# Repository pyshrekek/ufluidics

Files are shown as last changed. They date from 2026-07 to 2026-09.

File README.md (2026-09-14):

# ufluidics

Firmware for an Elegoo Mega 2560 R3 driving five NEMA17 syringe pumps on a microfluidic device.

Two input pumps push a fixed total flow into the chip at a fixed ratio to each other.
Three output pumps withdraw exactly that same total, split three ways.
Two potentiometers set the output split live, and a maintained switch arms and disarms the system.

Mass balance holds by construction, not by tuning.
No pump is ever commanded directly: one total flow constant drives both inputs (by a fixed ratio) and all three outputs (by fractions that sum to 1.0).
There is one source of truth for flow in the entire program.

## Dependency

**AccelStepper** by Mike McCauley.
Arduino IDE: `Tools > Manage Libraries`, search "AccelStepper", install.

Used in constant-speed mode only.
`runSpeed()` is polled for all five pumps on every loop pass and no acceleration ramp is configured, because steady volumetric flow is the whole point and a ramp would corrupt the mass balance every time a pot moved.

## Repository layout

```
ufluidics/
  README.md          this file - the Mega firmware: wiring, calibration, verification
  HARDWARE.md        PCB spec for the ESP32-S3 revision

  arduino/ufluidics/ Mega 2560 firmware (Arduino IDE)
    ufluidics.ino
    config.h

  firmware/          ESP32-S3 firmware (PlatformIO) - see firmware/README.md
    platformio.ini
    include/config.h
    src/{flow,motion,main}
    data/            LittleFS web assets

  hardware/          KiCad project
    ufluidics.kicad_{pro,sch,pcb}
```

Two builds coexist deliberately: the Mega rig stays working while the ESP32 board is developed. `src/flow.cpp` in the ESP32 build is the AVR flow math ported without modification - see `firmware/README.md`.

**`arduino/ufluidics/` must keep that directory name.** The Arduino IDE requires a sketch folder named exactly after its `.ino`. The repository root can be named anything.

The three KiCad files must also keep a shared basename - that is a KiCad requirement, not a convention. Rename all three together or none.

## Configuration at a glance

At 1/16 microstepping with a 2 mm lead screw and a 14.5 mm syringe bore:

| Quantity | Value |
|---|---|
| steps/mm | 1600 |
| uL/mm | 165.13 |
| steps/uL | 9.69 |
| uL per step | 0.103 |
| Full 10 mL stroke | 60.6 mm, 96 893 steps |

Input flow is **fixed in firmware**, not pot-controlled:

| Pump | Flow | Share of total | Step rate |
|---|---|---|---|
| IN1 | 70 uL/min | 6.25% | 11.3 steps/s |
| IN2 | 1050 uL/min | 93.75% | 169.6 steps/s |
| **Total** | **1120 uL/min (1.12 mL/min)** | - | - |
| OUT3 at a 100% split (worst case) | 1120 uL/min | - | 180.9 steps/s |

The two pots only set how that fixed total is divided between the three outputs.

Flow is smooth: the 0.103 uL step quantum is delivered 11 to 181 times a second, so pulsatility is not a concern.
Peak rate is 181 steps/s against the 2000 steps/s ceiling - an 11x margin, and the shortest step interval is 5.5 ms.
That is comfortably inside where a polled step generator is accurate, so AccelStepper's loop-latency behaviour is not a practical concern at these rates.

### Barrel capacity is the binding constraint - read this

The mechanics are comfortable at these rates; the syringes are what limit a run.
Every barrel is currently 10 mL, and the 15:1 input ratio means they do not last remotely the same time:

| Pump | Flow | 10 mL barrel lasts |
|---|---|---|
| IN1 | 70 uL/min | 143 min |
| IN2 | 1050 uL/min | **9.5 min** |
| OUT3 at a 100% split | 1120 uL/min | **8.9 min** |

**IN2 is the limiting pump.** A 10 mL barrel gives it under a 10 minute run.

For both inputs to exhaust together, barrel volumes want the same 15:1 proportion as the flows - 10 mL on IN1 against 150 mL on IN2 would both run 143 minutes. A 60 mL syringe on IN2 gives 57 minutes, which is usually the practical sweet spot.
Nothing in firmware can extend this; it is a straight volume-over-rate limit.

The output side needs the same thought.
The three outputs collectively receive the full 1120 uL/min, so whichever fills first ends the run - and OUT3 can be handed up to 100% of it.

**Mixing barrel sizes needs a small firmware change.** `SYRINGE_ID_MM` and `SYRINGE_VOLUME_UL` are global today, one geometry shared by all five pumps, which is also what the end-of-travel check uses.
Making them per-pump arrays in the shape of `STEP_PIN[]` and `DIR_SIGN[]` is roughly a 20 line change across both files.

### Note on resolution

The A4988 microstep table tops out at 1/16 (MS1/MS2/MS3 all high); 1/32 is not reachable on that chip.

The 2 mm lead screw compensates for that.
Dropping from 8 mm to 2 mm pitch quadruples resolution at the same microstepping: each step displaces **0.103 uL** instead of 0.41 uL.
That is finer than a DRV8825 at 1/32 would have given on the old 8 mm screw, so the driver is not the limiting factor.

Set `MICROSTEPS` and `LEADSCREW_PITCH_MM` in `config.h` to match the hardware and every derived value follows automatically.

## Wiring

Pins are freely reassignable in `config.h`; nothing depends on a particular port.

| Signal | Pin | Notes |
|---|---|---|
| STEP 1-5 | D22, D23, D24, D25, D26 | `STEP_PIN[]` |
| DIR 1-5 | D30, D31, D32, D33, D34 | `DIR_PIN[]` |
| ENABLE | D28 | Shared across all five drivers, active LOW |
| RUN switch | D2 | Maintained/latching, closed to GND. Internal pullup |
| Pot A | A0 | Sets OUT1's share |
| Pot B | A1 | Sets OUT2's share |
| Status LED | D13 | Off = idle, solid = running, blinking = fault |

The RUN switch needs no pulldown or external pullup - `INPUT_PULLUP` handles it, and an open switch reads HIGH (idle).

Pots wire as dividers: outer legs to 5 V and GND, wiper to the analog pin.

Pump index order is `IN1, IN2, OUT1, OUT2, OUT3`.
OUT1 and OUT2 are pot-controlled; OUT3 absorbs the remainder, so it is the largest stream at typical settings.

### Power

- **Set each driver's Vref before connecting any motor.** For an A4988 with 0.1 ohm sense resistors, `Vref = Imax * 8 * Rsense`; a 1.5 A NEMA17 wants roughly 1.2 V. Getting this wrong at 24 V destroys drivers and cooks motors.
- 24 V goes to driver VMOT only. The Mega runs from USB or its own barrel jack.
- **Grounds must be common** between the 24 V supply and the Mega.
- Put a 100 uF electrolytic across VMOT/GND at each driver, close to the pins.
- Never hot-plug a stepper into a powered driver. It kills the output stage.
- Confirm the MS jumpers match `MICROSTEPS`. A mismatch scales every flow rate by 2x to 16x with no error indication anywhere.

## Operation

Load **input syringes full** and **output syringes empty** before arming.
The firmware tracks travel by counting steps from this assumed starting state; it has no way to sense actual plunger position.

The RUN control is a **maintained (latching) switch**, so its position is the request - the firmware follows the level rather than toggling on an edge.

- **Close** the switch to arm. The LED goes solid and the drivers energise.
- **Open** it to disarm.
- Turn any pot at any time. Total flow and the split update live without stopping flow.
- If any syringe reaches the end of its stroke, the system halts itself, disables the drivers, blinks the LED, and prints which pump hit the limit. Open the switch to acknowledge - that resets the volume accounting and returns to idle, so it must not happen without an actual syringe reload.

**The system will not arm on power-up from an already-closed switch.** The switch has to be seen open at least once first (`g_armInhibit`). Without that, restoring power to a rig left switched on would start pumping with nobody present and with syringe positions assumed rather than known. The banner prints `[arm] RUN switch open, ready to arm` once the interlock clears.

Serial telemetry runs at **115200 baud**, one line per second:

```
state   OUT1/OUT2/OUT3 split   then per pump: uL/min (syringe uL)
RUN     50.0/30.0/20.0%   IN1 100.0(9987) IN2 1000.0(9871) OUT1 550.0(129) OUT2 330.0(77) OUT3 220.0(51)
```

The column header re-emits every 20 rows (`TELEMETRY_HEADER_ROWS`), so opening the serial monitor after boot still tells you what the numbers are - no reset needed.
Inputs report volume **remaining** in the barrel, outputs report volume **accumulated**.

The boot banner prints `uL per step`, both fixed input flows with their step rates, the input ratio, total flow, and the fastest pump's rate. Those are the numbers that tell you whether the mechanics suit the configured flow.

## Details worth knowing

**Telemetry is non-blocking.**
`Serial.print()` blocks once the 64-byte UART buffer fills, and anything that blocks stops `runSpeed()` from being polled.
AccelStepper timestamps each step as it happens rather than against a fixed schedule (its own source comments "does not account for costs in step()"), so a stalled loop turns directly into lost volume that is never made up.
Status lines are therefore staged in a buffer and drained only as fast as the UART has room.
A slow terminal throttles telemetry instead of corrupting flow.

**Both speed limits are enforced at compile time.**
`AccelStepper::setSpeed()` silently clamps against `setMaxSpeed()`, so a too-fast configuration would quietly under-deliver with no visible symptom.
`static_assert`s in `config.h` check the fastest possible pump (`MAX_PUMP_SPS`, OUT3 at a 100% split) and the slowest (`MIN_IN1_SPS`, always IN1) against the configured flow.
A wide input ratio squeezes both ends of that window at once, which is why the checks are paired: raising `IN2_TO_IN1_RATIO` pushes IN2 toward the ceiling and IN1 toward the floor simultaneously.

**The pot span has margins at both ends, and they are required.**
`POT_DEADBAND` only lets the applied value move once the reading shifts by more than 8 counts.
At the ends of travel there is nothing beyond to push it those last counts, so it strands short of the rail and 0%/100% become unreachable - the symptom is OUT3 bottoming out around 10.6% instead of 10.0% and topping out at 99.5% instead of 100%.
Real pots compound it, since track end resistance often stops the wiper reading a true 0 or 1023.
`POT_RAW_MIN`/`POT_RAW_MAX` discard the outer counts of the sweep so both rails are always reachable, and a `static_assert` enforces that the margin clears the deadband.

**There is a minimum speed, and it is a correctness limit.**
`setSpeed()` computes `_stepInterval = 1000000.0 / speed` into an `unsigned long`.
At 1 uL/min a pot near the bottom of its travel can command about 7.1e-5 steps/s, which works out to an interval of 1.4e10 us against a uint32 ceiling of 4.29e9.
It wraps, and the pump then runs roughly 3x **faster** than commanded rather than slower.
`applySpeeds()` therefore floors anything below `MIN_SPEED_SPS` to a true stop.
Verified against the library source, not assumed.

## Tuning

Everything of interest is in `config.h`:

```c
#define IN1_FLOW_UL_MIN       70.0f   // fixed; IN1 takes 1/16 of total
#define IN2_TO_IN1_RATIO      15.0f   // -> IN2 1050, total 1120 uL/min
#define OUT_POT_MAX_FRAC   0.45f   // per-pot ceiling; OUT3 floor is 1 - 2x this
#define SYRINGE_ID_MM      14.5f   // MEASURE THIS
#define MICROSTEPS         16      // must match the driver jumpers
#define LEADSCREW_PITCH_MM 2.0f    // must match the actual screw
#define POT_RAW_MIN        16      // pot end margins; must exceed POT_DEADBAND
#define POT_RAW_MAX        1007
```

If a pump runs backwards, flip its entry in `DIR_SIGN[]`.
Do not rewire.

## Verification

1. **Compile.** Arduino IDE with the board set to Arduino Mega 2560, or `arduino-cli compile --fqbn arduino:avr:mega .`
2. **Bench test with no motors and no 24 V.** USB power only. Open the serial monitor, confirm the arm interlock reports the switch open, close the switch, sweep both pots. The three output percentages must always sum to 100.0. Both pots at minimum must give OUT3 exactly 100.0%, both at maximum exactly 10.0%. If the endpoints come up short (10.6%, 99.5%), the pot end margins are too small - raise `POT_RAW_MIN` and lower `POT_RAW_MAX`.
3. **Watch the STEP pins** on D22-D26 before any liquid is involved. At 1 uL/min this is not a scope measurement - it is one pulse every 12.4 s on each input pump, so an LED on the pin or a logic analyzer in single-shot is the practical tool. Count the interval against the boot banner. This is the only way to catch a microstepping jumper mismatch or a wrong `LEADSCREW_PITCH_MM`, which are otherwise completely invisible.
4. **Dry motor run** with motors off the lead screws and 24 V on. The two input motors turn one way, the three outputs the other. Expect visibly discrete steps, not rotation - that is the flow rate, not a fault.
4b. **Sanity-check the timing before trusting a long run.** Not needed at these rates - the pumps step 16 to 291 times a second, so behaviour is observable in real time. Debugging a system that steps twice a minute is otherwise very slow going.
5. **Gravimetric calibration.** This is the test that validates the whole chain. Run one input pump alone for a timed 60 s into a tared weigh boat and compare mass in mg against expected uL. A consistent percentage error means `SYRINGE_ID_MM` is wrong; correct it and the error disappears from all five pumps at once, because everything derives from that one constant.
6. **Fault check.** Temporarily set `SYRINGE_VOLUME_UL` to 200, run, and confirm the system halts and blinks on schedule.

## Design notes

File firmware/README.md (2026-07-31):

# ufluidics firmware - ESP32-S3

PlatformIO project for the PCB revision. See `../HARDWARE.md` for the board spec and `../arduino/ufluidics/` for the original Mega firmware this was ported from.

## Build and flash

```sh
cd firmware
pio run                 # build
pio run -t upload       # flash over native USB
pio device monitor      # 115200, console is USB CDC
```

No USB-serial adapter is involved - the ESP32-S3 enumerates directly, which is what removes the CP2102N from the BOM.

## Layout

| Path | Contents |
|---|---|
| `include/config.h` | Every tunable constant, the pin map, and the compile-time sanity checks |
| `src/flow.{h,cpp}` | **Portable core**: flow math, pot conditioning, state enum. No hardware calls |
| `src/motion.{h,cpp}` | DDS step generator on a hardware timer |
| `src/main.cpp` | I/O, state machine, telemetry, task setup |
| `data/` | LittleFS image for web assets (`pio run -t uploadfs`) |

`flow.cpp` moved from the AVR build without modification. That is deliberate - it is the part that took the most iterations to get right, and keeping it free of hardware calls is what let it survive the port. If it ever needs `<Arduino.h>` for anything beyond the config constants, something belongs in `main.cpp` instead.

## Why a DDS instead of a stepper library

Each pump owns a 32-bit phase accumulator advanced on a 20 kHz timer interrupt; one step is emitted per accumulator wrap. Average rate is exact to about 5e-6 steps/s.

The AVR build used AccelStepper, which steps only when the main loop polls it and timestamps from the moment the step actually happened - its own source notes `_lastStepTime = time; // Caution: does not account for costs in step()`. Lateness therefore accumulates rather than averaging out, so anything that stalls the loop becomes permanently lost volume. That drove real complexity in the AVR firmware: non-blocking telemetry staging, round-robin ADC reads, a minimum-speed guard against interval overflow.

None of that is needed here. With a WiFi stack and a web server sharing the chip, a polled generator would have been a liability.

At peak the system runs 181 steps/s - about 111 timer ticks per step. FastAccelStepper's per-variant channel limits (4 steppers on ESP32-S3 under IDF 5.3+) are what would otherwise have forced the MCU choice; a DDS makes them irrelevant.

## Notes that will bite if forgotten

**Pots must be on ADC1 (GPIO1-10).** ADC2 does not work while WiFi is active. Silicon limitation, not a firmware workaround.

**The ADC is 12-bit here, 10-bit on the Mega.** Every pot constant derives from `ADC_MAX_COUNT` for that reason. Hardcoding the AVR values would make `PotFilter::fraction()` saturate at a quarter of pot travel, pinning OUT1/OUT2 to maximum over three quarters of the sweep with no error reported anywhere.

**STEP pins must stay above GPIO32 and contiguous.** The ISR writes `GPIO_OUT1_W1TS`/`W1TC` once for all five pumps. A `static_assert` enforces the bank; the contiguity is by convention.

**GPIO22-34 do not exist on the WROOM-1 module** - the pads jump from IO21 to IO35. A `PIN_EXISTS()` `static_assert` covers every assigned pin, because a non-existent pin yields a schematic net going nowhere rather than any build or DRC error.

**The pin map avoids GPIO35-37 so it serves both N16 and N16R8.** Octal PSRAM claims that range for the SPI0/1 data lines. Only the optional SPI display header uses it, and that header is compiled out when `BOARD_HAS_PSRAM` is defined. A guarded `static_assert` fails the build if any other pin strays in there - verified by deliberately breaking it, not just written and hoped for.

Build for an R8 part with:

```sh
PLATFORMIO_BUILD_FLAGS="-DBOARD_HAS_PSRAM" pio run
```

**The ISR must stay in IRAM and out of flash.** No `digitalWrite`, no `gpio_set_level`, no logging inside `ddsIsr()`. The register macros used there are volatile stores and are safe.

**The platform version is pinned on purpose.** arduino-esp32 3.x renamed the entire timer API; `motion.cpp` compiles against both via `ESP_ARDUINO_VERSION_MAJOR`, but which one you build with should be a decision rather than an accident.

## Not yet implemented

Marked `TODO` in `main.cpp`:

- TMC2209 UART setup - RMS current, 1/16 with MicroPlyer interpolation, StealthChop. Two buses, since a 2-bit MS1/MS2 address means one bus reaches only four drivers.
- WiFi (AP mode with WPA2) and the async web server with WebSocket telemetry.
- Endstop homing, which turns the travel limit from an assumption about starting position into a measurement.
- Per-pump syringe geometry. Currently one `SYRINGE_ID_MM` for all five, which with a 15:1 input ratio gives very different barrel lifetimes.
- Calibration persistence in NVS.

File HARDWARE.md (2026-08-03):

# ufluidics - PCB hardware specification

Target: a single board carrying five stepper drivers, an MCU, and a web interface, replacing the Mega + A4988 breakout build.

KiCad project lives in `hardware/`. Net-by-net wiring is in [hardware/CONNECTIONS.md](hardware/CONNECTIONS.md).

## MCU selection

### First: the constraint everyone assumes is binding, is not

The obvious way to choose is by counting hardware step channels, since FastAccelStepper's support varies sharply by chip:

| Variant | Hardware step channels (FastAccelStepper) |
|---|---|
| ESP32 (classic) | 14 (6 MCPWM/PCNT + 8 RMT) |
| ESP32-S3 | 8 on IDF 4.x, **4** on IDF 5.3+ |
| ESP32-S2 / C3 / C6 | 4 / 2 / 2 |
| RP2040 (Pico W) | 4 under the Arduino core |
| RP2350 (Pico 2 W) | 8 under the Arduino core |

By that table only classic ESP32 and RP2350 clear five pumps, and ESP32-S3 is a trap - it advertises 8 but drops to 4 on IDF 5.3+, so a routine toolchain bump breaks the build.

**But this project does not need any of it.** Two facts collapse the constraint:

1. **Drive the TMC2209 at 1/16 with MicroPlyer interpolation to 1/256**, rather than 1/256 natively. The driver interpolates internally, so you get 1/256 smoothness at 1/16 step rates. Native 1/256 would multiply every rate by 16 for no benefit.
2. At that setting the **peak rate across the whole system is 181 steps/s** (OUT3 at a 100% split, current flow config).

A DDS step generator on a 20 kHz hardware-timer ISR - five 32-bit phase accumulators, one step per accumulator wrap - gives **111 timer ticks per step at peak** and a rate resolution of 5e-6 steps/s. On a 240 MHz dual-core part with the motion task pinned to core 1, that is not close to a limit.

This design was written and bench-compiled for the Mega early in this project, then replaced by AccelStepper before the repository existed - so it predates git history and has to be rewritten rather than recovered. It is roughly 40 lines.

So: **use a timer DDS, not FastAccelStepper**, and the per-variant channel table stops mattering. The MCU can then be chosen on the things that actually shape the board - GPIO count, ADC behaviour, USB, ecosystem.

### The choice

| | ESP32-WROOM-32E | **ESP32-S3-WROOM-1-N16** | RP2350B |
|---|---|---|---|
| Usable GPIO | 19 out + 4 in-only | **30** | 48 |
| I/O expander needed | **Yes** | No | No |
| ADC usable with WiFi | ADC1 only, 6 ch | **ADC1, 10 ch** | All, no conflict |
| Native USB | No - needs CP2102N | **Yes** | Yes |
| WiFi | Mature, on-die | **Mature, on-die** | External CYW43439 |
| Web stack maturity | Best | Best | Weaker (lwIP via arduino-pico) |
| Cost | ~$3 | ~$4 | ~$2 + radio |

**Recommendation: ESP32-S3-WROOM-1-N16.**

It wins on three concrete things:

- **30 usable GPIO deletes the MCP23017.** The module exposes GPIO0-21 and GPIO35-48 (36 pins); reserving GPIO19/20 for USB and GPIO0/3/45/46 as strapping leaves 30. The pin budget that forced an expander was a classic-ESP32 problem, not an ESP32 problem.
- **Native USB deletes the CP2102N**, its crystal and its support parts. Programming and console come straight off USB-C, and DFU becomes available.
- **ADC1 has 10 channels on GPIO1-10 and works with WiFi up.** Classic ESP32 gives you 6, overlapping the input-only pins the endstops want. That collision was the other half of the pin problem.

**N16 is preferred, but the firmware pin map works on either.** Octal PSRAM (the R8 parts) consumes GPIO35-37 for the SPI0/1 data lines, so `firmware/include/config.h` keeps everything except the optional SPI display header clear of that range. A `static_assert` guarded by `BOARD_HAS_PSRAM` fails the build if a pin ever strays into it, rather than letting the board fight its own memory bus at run time.

What you give up on R8:

| | N16 | N16R8 |
|---|---|---|
| Usable GPIO | 30 | 27 |
| Pins used by this design | 26 | 26 |
| Spare | 4 (35, 36, 37, 48) | 1 (48) |
| SPI display header (GPIO35-37) | Available | **Not available - use I2C** |

The 8 MB of PSRAM buys nothing here. A single-page web UI is a few hundred KB, the build currently uses 5.9% of SRAM, and an ILI9341 driven by Adafruit_GFX draws directly rather than from a framebuffer. So R8 costs five GPIO and the SPI display option in exchange for memory this design does not use - but if it is what you can get, it works.

RP2350B is technically the most elegant - PIO state machines are purpose-built for exactly this - but the WiFi is a separate CYW43439 die and the Arduino web stack is meaningfully less mature. Not worth it when step generation is a solved non-problem.

**Fallback:** if you would rather not move, classic ESP32 + MCP23017 works and is fully specified below. It is a proven, boring design. It just costs an extra chip and eight pins of headroom to reach the same place.

### Do you need a Raspberry Pi?

No, and adding one makes things worse.

Linux has no hardware step generation on GPIO and no real-time guarantee, so a Pi driving steppers directly produces visible flow jitter. You would end up with a Pi for the UI plus an MCU for motion - two processors, an inter-processor protocol, and two firmware images to keep in sync.

The ESP32 serves the web UI itself. Add a Pi only if you later want camera capture, long-term database logging, or on-box Python analysis - and then it talks to the ESP32 over HTTP/MQTT and stays out of the motion path.

## Bill of materials

### Controller

| Item | Part | Qty | Notes |
|---|---|---|---|
| MCU module | **ESP32-S3-WROOM-1-N16** | 1 | 16 MB flash. N16R8 also works but costs GPIO35-37, hence the SPI display header |
| USB-serial | **none** | 0 | ESP32-S3 has native USB. Wire D+/D- to GPIO20/19 |
| USB connector | USB-C receptacle | 1 | 5.1k pulldowns on both CC pins |
| Auto-reset | 2x transistor (DTR/RTS) | 1 set | Only if you also fit a serial header; native USB does not need it |
| Boot/reset buttons | Tactile SMD | 2 | GPIO0 needs 10k to 3V3; EN needs 10k + 1 uF |
| Crystal / oscillator | **none** | 0 | 40 MHz crystal, flash and RF matching are inside the module |

### Stepper drivers

**TMC2209, five off.** This is a significant upgrade over the A4988 and fixes several problems in the current build at once.

| Advantage | What it fixes |
|---|---|
| 1/256 microstepping with MicroPlyer interpolation | 16x finer than the A4988's 1/16 ceiling. Step quantum drops from 0.103 uL to 0.0065 uL |
| Current set over UART, in software | **Removes the Vref trimpot entirely** - the single most dangerous step in the current build, where a mis-set pot destroys drivers at 24 V |
| StealthChop2 | Near-silent. Matters in a lab, and reduces vibration coupling into the fluidics |
| StallGuard4 | Sensorless endstop detection, optional backup to mechanical switches |
| CoolStep | Cuts idle current and heat |
| 4.75-29 V VM | 24 V is comfortably in range |

Current rating is 1.4 A RMS / 2 A peak, which suits a 42 mm NEMA17 driving a 2 mm lead screw. Syringe plunger force is modest and the screw's mechanical advantage is large, so this is not marginal.

If you later need more force, TMC5160 (SPI, external MOSFETs) is the step up. Do not use it unless measurement says you need it.

**UART addressing detail that affects the schematic:** a TMC2209 takes a 2-bit address from MS1/MS2, so **one UART line addresses four drivers**. For five you need a second bus. On the ESP32-S3 the console runs over native USB, which frees all three hardware UARTs - use two of them and do not try to put all five drivers on one bus.

| Item | Part | Qty |
|---|---|---|
| Driver | **BigTreeTech TMC2209 V1.2/V1.3** module, socketed | 5 |
| Driver sockets | 2x8 female header, 0.1 in, per driver | 10 |
| Driver decoupling | 100 uF electrolytic + 100 nF, per driver, close to VS/VMOT | 5 sets |

**Socketed modules**, on 2x8 female headers. A failed driver becomes a swap rather than a rework, which matters while the rig is being commissioned.

This also removes about forty passives from the BOM: the charge pump capacitors, the 5VOUT regulator capacitor and all ten sense resistors live on the module. Only the 100 uF + 100 nF per socket on VMOT stays.

The cost is two failure modes sockets introduce - a module can be inserted backwards, and a module can be hot-plugged. Both destroy the driver, and a reversed one can take the MCU with it. Silkscreen the outline, pin 1 and the VMOT end, and mark the board "power off before swapping".

### Power

24 V in, with 5 V and 3.3 V derived on board.

| Item | Part | Notes |
|---|---|---|
| Input connector | 5.08 mm screw terminal, 2-pin | Or barrel jack; terminal is more secure |
| Fuse | **2 A time-lag**, 5x20 mm cartridge in a PCB holder | Sized to the load, not the PSU - see below |
| Reverse polarity | P-MOSFET (e.g. SI2333) in the high side | Better than a Schottky - no 0.5 V drop, no heat |
| Input TVS | SMBJ26A | Clamps inductive kickback from motor leads |
| Bulk cap | 470-1000 uF, 35 V, low ESR | Plus the per-driver 100 uF above |
| 24 V -> 5 V | **Recom R-78HB5.0-1.0** module (9-72 V in, 5 V 1 A, SIP-3) | One part, no external components. See below |
| 5 V -> 3.3 V | **AP7361C-33E-13**, SOT-223 | 1 A, 140 mV dropout at 300 mA. Low dropout is required - see below |
| LDO input cap | 1 uF X7R at the AP7361C VIN pin | Datasheet minimum. Separate from the 5 V bulk |
| LDO output cap | 1 uF X7R at the AP7361C VOUT pin | Datasheet minimum for loop stability. The 22 uF at the module is bulk, not a substitute |
| 3.3 V bulk | 22 uF + 100 nF at the module | Espressif minimum is 10 uF; WiFi TX is bursty |
| EN delay | 10k to 3V3 + **1 uF** to GND | Espressif's recommended RC. See below |

### The EN cap is 1 uF, not 100 nF

EN (CHIP_PU, pad 3) must rise *after* the 3.3 V rail is valid. The 10k pullup and the cap to ground form the delay that guarantees it, and Espressif's hardware design guidelines name the values: "The recommended setting for the RC delay circuit is usually R = 10 kOhm and C = 1 uF."

100 nF gives a 1 ms time constant. That is short enough to lose the race against a slow supply ramp, and the failure is the worst kind - intermittent. A board that boots on the bench and fails one power-up in twenty, or that occasionally fails to finish a flash erase, is this circuit. 1 uF gives about 10 ms and costs nothing.

If it still misbehaves - a very slow ramp, or a rail that browns out rather than dropping cleanly - the guidelines' next step is a dedicated power-monitor/supervisor IC holding EN low below about 3.0 V. Leave a footprint for one rather than tuning the RC upward forever.

The reset button sits across the same cap, discharging 1 uF through the switch contacts. That is harmless at this size and needs no series resistor.

**BOOT (GPIO0) does not get an RC - pull-up and button only.** The two pins look symmetric and are not. EN's capacitor buys a delay; GPIO0 has no delay to buy, because it is sampled once on the reset release edge and either reads high or low. A capacitor there changes nothing about that sample, slows the pin if GPIO0 is ever repurposed as an output, and on any board carrying an auto-reset transistor pair it breaks download-mode entry. This board has no auto-reset circuit - native USB makes it unnecessary - so a cap would be merely useless, which is still the wrong thing to leave on a strapping pin for the next revision to puzzle over.

Entry to download mode is unchanged: hold BOOT, tap RESET, release BOOT. The 1 uF makes reset release lag the button by about 10 ms, far inside human timing.

### Power budget

| Rail | Average | Peak |
|---|---|---|
| 3.3 V | 215 mA (ESP32 120, display 80, VIO x5 5, LEDs 10) | 595 mA (ESP32 WiFi TX burst) |
| 5 V | 215 mA, all of it feeding the LDO | 595 mA |
| From 24 V for logic | **~53 mA** | ~150 mA |

Logic draw off the 24 V rail is trivial next to the motors. A 3 A buck is 3-4x oversized, which is deliberate: margin is nearly free and covers a fan later.

**The display's 80 mA is the softest number in that table**, and almost all of it is backlight. Measured 2.4" ILI9341 modules land anywhere from 60 to 110 mA depending on the series resistor the vendor fitted. The design absorbs the top of that range without changes: at 110 mA the 3.3 V average becomes 245 mA, the LDO burns 0.42 W instead of 0.37 W, and the SOT-223 junction rise goes from +20 C to +22 C. Worth measuring your module, not worth redesigning around.

### Buck: use a module, not a discrete design

At 215 mA average the logic rail is a trivial load, and a discrete switcher earns nothing for it. Compare:

| | Recom R-78HB5.0-1.0 | TPS54360 discrete |
|---|---|---|
| Input range | **9-72 V** | 4.5-60 V |
| Output | 5 V, 1 A | 5 V, 3.5 A |
| External components | **1 (the module)** | ~16 |
| Layout risk | None - shielded module | High di/dt loop, must be tight |
| Protection | Thermal shutdown + short circuit, built in | Built in, but yours to lay out |
| Cost | ~$10 | ~$4 |

For a low-volume instrument the module is the obvious trade: about six dollars buys away fifteen components, a critical layout, and a whole category of bring-up debugging. It is SIP-3 and pin-compatible with an LM7805.

**Specify the 1.0 A version, not the 0.5 A.** Peak draw is about 595 mA (ESP32 Wi-Fi transmit, display, LEDs). Riding a 95 mA deficit through a 2 ms burst on bulk capacitance would need roughly 1900 uF to hold droop under 100 mV - not worth it when the 1 A part sits at 60% of rating and needs nothing.

The 9-72 V input range also delivers the voltage margin argued for below, without having to reason about it: a 24 V motor rail with back-EMF and hot-unplug transients is nowhere near 72 V.

Traco **TSR 1-2450** (6.5-36 V, 1 A) is an equivalent alternative, with less input margin.

#### If the board is JLCPCB-assembled

The Recom is SIP-3 through-hole and is unlikely to be in JLC's library at all. Two ways round it:

**Keep the module and hand-solder it.** Mark it DNP in the assembly BOM, place the footprint, and fit it yourself - it is three through-hole pins. JLC assembles everything else. This keeps the 72 V input margin and the one-component simplicity, and costs about thirty seconds at the bench. For a low-volume instrument this is usually the right answer.

**Or switch to an SMD part JLC stocks.** Selection criteria, in priority order:

1. **Input rating 40 V minimum** - the rail is shared with five inductive loads
2. 600 mA or more output (595 mA peak)
3. Internally compensated, to avoid a COMP network
4. Fixed 5 V, to avoid a feedback divider

Candidates worth checking against the live library at `jlcpcb.com/parts`:

| Part | Vin | Iout | Freq | Notes |
|---|---|---|---|---|
| **LM2675MX-5.0/NOPB** | 40 V | 1 A | 260 kHz | SOIC-8, internally compensated, fixed 5 V. Best of these if stocked |
| **XL1509-5.0E1** (LCSC C61063) | 40 V | 2 A | 150 kHz | SOP-8, about $0.11, near-certain LCSC stock. Low frequency means a bulky inductor |
| **MP4560** | 55 V | 3 A | adjustable | Better input margin; MPS parts are generally well stocked at LCSC |

Stock moves, and it cannot be checked from here - verify on JLC's parts search before committing the schematic. Extended parts carry a small per-part setup fee but are otherwise fine.

Note that all of the 40 V candidates sit at the stated minimum rather than comfortable margin. Keep the input TVS regardless, and prefer the 55 V option if it is available.

#### Middle option: LM2675MX-5.0

If SMD assembly or part cost matters more than component count, the **LM2675MX-5.0/NOPB** sits between the module and a full discrete design: 6.5-40 V in, 1 A, 260 kHz fixed, internally compensated, and the fixed-5.0 V version needs no feedback divider.

| | R-78HB5.0-1.0 | LM2675MX-5.0 | TPS54360 |
|---|---|---|---|
| Vin max | **72 V** | 40 V | 60 V |
| Output | 1 A | 1 A | 3.5 A |
| External parts | **1** | ~6 | ~16 |
| Catch diode | none | required | required |
| Compensation | none | internal | external RC |
| Feedback divider | none | none (fixed) | 2 resistors |
| Package | SIP-3 through-hole | SOIC-8 | SOIC-8 |
| Cost | ~$10 | ~$3 | ~$4 |

External parts are Cin, Cout, inductor, catch diode (1 A 40 V Schottky) and a ~10 nF bootstrap capacitor. That removes the two worst parts of the TPS54360 design - the compensation network and the feedback divider.

Two caveats:

- **40 V is the stated minimum, not comfortable margin.** With the input TVS clamping around 26-29 V there is roughly 11 V of headroom on a rail shared with five inductive loads. This is the same argument that ruled out TPS54331 and MP1584, and the LM2675 only just clears it.
- **260 kHz is slow, so the inductor is bulky.** Around 33 uH keeps continuous conduction at the 250 mA load with 24 V in; the datasheet nomograph suggests more for the full 1 A rating.

It also still has a catch diode, so the high-di/dt loop still needs a tight layout. Fewer support components does not remove that risk - only the module does.

##### LM2675 pin wiring (8-SOIC: 1 CB, 2 NC, 3 NC, 4 FB, 5 ON/OFF, 6 GND, 7 VIN, 8 VSW)

| Pin | Wire to |
|---|---|
| VSW (8) | Inductor, **and** the catch diode cathode. 1 A 40 V Schottky, anode to GND |
| CB (1) | 0.01 uF to **VSW**, not to GND - the bootstrap rides on the switch node |
| FB (4) | Directly to the **+5 V output** at the output capacitor. No divider; the fixed-5.0 version has it internally, confirmed by the datasheet spec'ing feedback bias current as "ADJ Version Only". Route as a sense line away from VSW |
| ON/OFF (5) | **Leave floating for always-on**, or drive from a 3.3 V GPIO. Active HIGH |
| GND (6) | Ground plane |
| VIN (7) | +24 V, input capacitors close |
| NC (2, 3) | No connect |

**ON/OFF polarity is resolved: active HIGH.** SNVS129G (rev June 2025) Table 4-1 states "Enable input to the voltage regulator. High = ON and low = OFF. Pull this pin high or float to enable the regulator." Section 6.4 repeats it: below 1.4 V is shutdown at 20 uA standby, above 1.4 V the device switches. The pin sources its own bias current (Figure 5-9, "ON/OFF Pin Current (Sourcing)", ~20 uA typical), which is why floating reads as HIGH. The overbar in the symbol is a family-inherited artifact; it does not match this part's own text.

So the three-resistor pad plan is unnecessary. Two options:

- **Always on:** float the pin. No parts.
- **MCU shutdown control:** drive pin 5 from a 3.3 V GPIO. That clears the 2.0 V worst-case threshold with margin and stays under the 6 V absolute maximum. Add a 100 k pulldown if the rail must stay off while the GPIO is tri-stated during ESP32 boot - the pin's own source current will otherwise pull it up.

Two constraints regardless:

- **Never tie ON/OFF to VIN.** Absolute maximum on that pin is **6 V** against a 24 V rail. This destroys the part immediately.
- **Never tie it to the 5 V output.** The output is 0 V at power-up, so the regulator would never start.

Fit a divider from VIN only if input UVLO is wanted for its own sake (roughly 30 k / 4.3 k gives about 3.3 V at 24 V in and will not start below about 16 V). Keep it stiff - tens of kilohms, not hundreds - so the pin's 20 uA source current does not shift the node, and check the node stays under 6 V at worst-case VIN.

##### LM2675 external components for 24 V -> 5 V

| Part | Value | Note |
|---|---|---|
| L1 | 68 uH, Isat >= 2.2 A | 5 V nomograph (datasheet Figure 7-4) at 24 V in. Isat must clear the 2.2 A max current limit, not the load |
| D1 | 1 A 40 V Schottky, e.g. SS14 / B140 / MBRS140 | Reverse rating >= 1.25x max VIN. Anode to GND, cathode to VSW |
| CIN | 22 uF 50 V low-ESR, plus 0.1 uF ceramic at pin 7 | RMS current rating >= half the DC load current |
| COUT | 47-68 uF **with ESR**, tantalum or polymer | See below |
| CB | 0.01 uF 50 V ceramic | CB to VSW |

**Do not use an all-ceramic output capacitor.** The LM2675 is voltage-mode and internally compensated around output-capacitor ESR; every capacitor in the datasheet's selection tables is a solid tantalum. An X5R/X7R output with milliohm ESR moves the ESR zero out of the loop and can ring or oscillate. Use a tantalum or polymer part, or add a small series resistance.

Note the datasheet contradicts itself on CB: Table 4-1 says 470 nF, while every application circuit and design example says 0.01 uF. Follow the application circuits.

Go full discrete (TPS54360, documented below) only if you later need more than 1 A or reach volumes where part cost dominates.

### Discrete alternative: why 40 V minimum

Common parts sized "for 24 V" - TPS54331, MP1584, AP63203, TPS54202 - are rated 28-32 V. On a rail shared with five inductive loads, motor back-EMF and hot-unplug transients exceed that. The failure mode is a shorted high-side FET putting 24 V onto the 5 V rail and through everything downstream.

**TPS54360** is the recommended part: 4.5-60 V, 3.5 A, adjustable 100 kHz - 2.5 MHz, SOIC-8 PowerPAD. The 60 V rating is generous margin, and TI WEBENCH will generate the inductor, capacitors, feedback divider and a layout for your exact operating point - worth using rather than hand-picking values.

Set the switching frequency around 400-600 kHz. Higher shrinks the inductor but pushes more high-frequency energy at the ADC; lower needs a bulkier inductor.

For a first spin, a soldered-down pre-made 24 V -> 5 V buck module is a legitimate way to avoid designing a switcher at all.

### LDO: sized by dissipation, not by part number

At 215 mA average from 5 V the LDO burns **0.37 W**. That average is what sets junction temperature - the ESP32's WiFi bursts are milliseconds against a package thermal time constant of seconds, so the junction cannot follow them and peak current is not the sizing case.

Thermal resistance depends on the package **and** the copper under it:

| Package | Theta JA | Rise at 0.37 W | Junction at 25 C ambient |
|---|---|---|---|
| SOT-23-5 | ~250 C/W | +93 C | **118 C** - too hot, and worse inside an enclosure |
| SOT-223, good pour | ~53 C/W | +20 C | 45 C |
| SOT-223, minimal copper | ~150 C/W | +56 C | 81 C - works, runs warm |
| DPAK | ~40 C/W | +15 C | 40 C |

So the requirement is: **a part rated 600 mA or more, in a package that sheds 0.4 W on the copper you actually give it.** SOT-223 with a pour or DPAK both satisfy that.

AP2112K and RT9013 are ruled out not because SOT-23-5 is inherently wrong but because that is the only package they come in.

#### Dropout also matters, because of the USB path

The obvious picks - NCP1117, TLV1117, AMS1117 - are all ~1 V dropout parts, and that fails when the board runs on USB alone:

```
USB VBUS, spec minimum at the device        4.75 V
  - VBUS Schottky Vf at 250 mA             -0.35 V
  - 1117-family dropout at 250 mA          -1.00 V
  = 3.40 V                                  only 100 mV of margin
```

A long cable, a tired port or a hub eats that. The symptom is an ESP32 that resets during Wi-Fi transmit bursts, which looks exactly like a firmware bug and is miserable to chase.

**AP7361C-33E-13** fixes it: 140 mV dropout at 300 mA, 1 A, SOT-223, with current limit and thermal shutdown built in. Same package and the same 0.37 W, so the thermal analysis above is unchanged, and margin goes from 100 mV to about 960 mV.

Input range is 2.2-6 V, which covers both the 5.1 V buck output and a 5.25 V VBUS.

With 24 V present none of this matters - the buck holds 5.1 V and any of these parts would be fine. It is only the USB-only case that is tight, and USB-only is a state worth keeping usable.

### TPS54360 pin-by-pin

Values below come from the TPS54360 datasheet (SLVSBB4G), whose own worked design example happens to be a 5 V output.

**The TPS54360 is non-synchronous.** It "requires an external catch diode between the SW terminal and GND" - a Schottky, cathode at SW, anode to GND, 60 V and 3 A or better (B360A, SS36). Omitting it is the most likely way to end up with a board that does not switch.

| Pin | Wire to | Value |
|---|---|---|
| 1 BOOT | Capacitor to **SW** (not to GND) | 0.1 uF, X5R or better, 10 V+ |
| 2 VIN | +24 V | Input capacitors as close as possible |
| 3 EN | Divider from VIN to GND | 887k / 53.6k -> UVLO on at 20 V, off at 17 V |
| 4 RT/CLK | Resistor to GND | **162 k = 600 kHz** (the datasheet's own value) |
| 5 FB | Divider tap from +5 V | **53.6 k top / 10.2 k bottom -> 5.004 V** |
| 6 COMP | Series R+C to GND, small C in parallel | ~13 k + ~2.2 nF, ~12 pF parallel - **verify, see below** |
| 7 GND | Ground plane | |
| 8 SW | Inductor **and** catch diode cathode | 8.2 uH |
| 9 Thermal pad | GND, thermal vias | Datasheet: "must be electrically connected" |

The reference is 0.8 V, so `Vout = 0.8 x (1 + Rtop/Rbot)`. Frequency follows `RT(kohm) = 101756 x fSW(kHz)^-1.008`.

**EN floats to enable** - the datasheet says so explicitly. Do not rely on that. The divider gives input undervoltage lockout, which matters on a rail shared with five motors: without it the converter will try to start into a sagging supply.

**COMP is the one value not to copy blindly.** Compensation depends on the actual inductor and output capacitance, and TI's example runs 12 V in against our 24 V. Run WEBENCH at Vin = 24 V, Vout = 5 V for the R/C pair.

#### Operating point note

The logic rail draws about 250 mA from a 3.5 A part - **7% of rating**. Inductor ripple at 24 V in with 8.2 uH at 600 kHz is 0.80 A pk-pk, comfortably above the DC load, so the converter sits in discontinuous conduction and Eco-mode pulse-skipping essentially always. That is efficient and fine, but it means light-load behaviour matters more here than the load-step response TI's example is tuned for.

#### Layout

The high di/dt loop is VIN -> internal FET -> SW -> catch diode -> GND. Keep it physically tiny:

- Input capacitor across VIN and GND, as close to the pins as the footprint allows.
- Catch diode immediately at SW and GND, in the same loop.
- SW copper only as large as the current needs - it is the noisy node and radiates in proportion to its area.
- FB trace short, routed away from SW and the inductor, tapped at the output capacitor.
- Thermal pad to the ground plane with a via array.

Keep the whole switcher away from the analog corner. The pots feed a 12-bit ADC, and this is the loudest thing on the board.

### Why not go 24 V straight to 3.3 V

A single 24 V -> 3.3 V buck is feasible - the 13.7% duty at 500 kHz is within a TPS54360's minimum on-time - and it would be more efficient. Two reasons not to:

- **The LDO's PSRR is doing real work.** It filters switcher ripple out of the rail feeding a 12-bit ADC that reads the pots. Feeding the ESP32 directly from a switcher puts that ripple straight into the flow split.
- Nothing else on this board needs 5 V, but having the rail costs almost nothing and gives you a fan option.

### Power topology

The ESP32-WROOM module has **no onboard regulator** - that is a dev-board feature. On a custom PCB you need both stages:

```
24 V --[buck, 40V+ rated]--> 5 V --[LDO]--> 3.3 V --> ESP32
```

If you socket an ESP32 DevKitC instead of reflowing a bare module, it brings its own 3.3 V LDO, and you only need the 24 V -> 5 V stage feeding its 5 V/VIN pin. That is the lower-risk option for a first board spin.

**Never linear-regulate from 24 V.** At the ESP32's 500 mA WiFi peak, a 24 V -> 3.3 V linear regulator dissipates **10.4 W**. The same LDO from 5 V dissipates 0.85 W, which is why the intermediate rail exists. This is not an efficiency preference; it is the difference between a warm part and a fire.

**PSU sizing:** five motors at 24 V, chopper-driven, average maybe 0.5 A each into the drivers. Specify a **24 V 5 A (120 W)** supply. That is generous, and generous is correct for inductive loads.

### Input protection: fuse, then P-FET, then TVS

Order matters as much as the parts.

#### Sizing the fuse to the load, not to the PSU

A fuse chosen to match a 24 V 5 A supply protects the supply. The board draws far less, and the pumps run at constant low velocity, so the motors sit at holding current and the dominant term is I<sup>2</sup>R rather than acceleration:

| Term | Value |
|---|---|
| Per motor, two phases at 800 mA RMS into ~2 ohm | ~2.6 W |
| Plus driver loss | ~2.9 W, so **0.12 A at 24 V** |
| Five motors | ~0.6 A |
| Logic off the 24 V rail | 0.05 A |
| **Steady state total** | **~0.7 A** |

| Spec | Value | Why |
|---|---|---|
| Current | **2 A** | About 2x the load. Fuses derate to 75% of rating for continuous duty, giving 1.5 A usable against 0.7 A |
| Characteristic | **Time-lag (T)** | Must survive inrush into the 470-1000 uF bulk. A fast-blow opens on first power-up |
| Voltage | **>= 32 VDC**, not merely 250 VAC | An AC rating says nothing about extinguishing a DC arc - DC has no zero crossing to help |
| Breaking capacity | >= 35 A | Must exceed what the supply dumps into a dead short before its own protection folds back |
| Position | +24 V at J18, ahead of Q1 and the TVS | Return stays unfused |

Step to 3 A only if measured sustained draw exceeds about 1.3 A.

**Cartridge, not polyfuse.** A PPTC self-resets, which is the wrong trade here: it trips at roughly 2x hold current, its hold current derates about 50% by 70 C inside an enclosure, it adds 50-100 mohm in series with the motor supply, and it degrades on every trip. A cartridge fuse is deterministic, and a blown one is a diagnosable event rather than a rail that sags when the case gets warm.

**What the fuse is not for.** It does not protect the drivers or the MCU - silicon fails in microseconds and fuses in milliseconds. It protects the harness and the supply lead, and turns a shorted high-side FET into an open circuit instead of a fire. Reverse polarity is Q1's job. Put the rating in silkscreen next to the holder, or the next person fits whatever is in the drawer.

```
        J18+          F1 5A
   24V IN o---------/\/\/------+------- D  |     S -------+------ +24V rail
                                          |Q1 (P-ch)      |
                                          G               |
                               +----------+           [TVS SMBJ26A]
                               |          |               |
                            [Rg 100k]  [Dz 15V]      [C 470-1000uF]
                               |          | cathode to S,         |
   24V IN o-------------------+----------+ anode to G            |
        J18-                   GND                              GND
```

#### Drain toward the input, source toward the load

This reads backwards and is not. On a P-channel device the body diode runs anode-at-drain to cathode-at-source, so this orientation points it the way current normally flows.

- **Correct polarity:** at power-up the body diode conducts input to load, the rail reaches about 23.3 V, the gate sits near ground, Vgs is about -23 V and the FET turns hard on. The channel then shorts out its own body diode and the drop becomes I x Rds(on) - single-digit millivolts, against 0.5 V and 0.5 W for the Schottky this replaces.
- **Reversed:** the body diode is reverse-biased and blocks, and source and gate sit at nearly the same potential so Vgs is about 0 and the channel stays off. Nothing conducts anywhere on the board.

Wire it the other way - source to the input - and the reverse case forward-biases the body diode straight through the board. That arrangement is a reverse *current* blocker, a different function, and the two are confused constantly.

#### The gate clamp is mandatory

Vgs(max) is ±20 V on nearly every P-FET, and a bare gate-to-ground resistor puts the full 24 V across it. The oxide fails on first power-up. The 15 V Zener holds Vsg at 15 V, leaving the gate at about +9 V with the FET fully enhanced, and Rg limits Zener current.

#### SI2333 is the wrong part

It is a -30 V device. The TVS clamps at 26-29 V, so headroom on a rail that five motors dump back-EMF into is 1 to 4 V - the same argument that ruled out the 30 V buck candidates. Specify instead:

| Parameter | Target |
|---|---|
| Vds | **>= -60 V** |
| Vgs | ±20 V, hence the Zener |
| Id | >= 5 A |
| Rds(on) | <= 50 mΩ at Vgs = -10 V |

At roughly 1 A average the FET burns about 50 mW, so thermal design is not a consideration.

#### Part selection

| Ref | Spec | Candidates |
|---|---|---|
| Q1 | P-channel, Vds **>= -60 V**, Vgs ±20 V, Id >= 5 A, Rds(on) <= 50 mohm at Vgs = -10 V | SUD50P06-15 (-60 V, ~15 mohm, TO-252); IRFR5305 (-55 V, ~60 mohm, DPAK); IRF9540N (-100 V, TO-220) for through-hole |
| Rg | 100k, gate to GND | Any |
| Dz | 15 V Zener, 500 mW, gate to source. Cathode at source | BZT52C15 (SOD-123) |
| TVS | **SMBJ26A**, unidirectional, 600 W, SMB | Keep this one - see below |

Verify stock against JLC's live library before committing; Rds(on) is not the binding constraint at 1 A, so substitute freely on that axis but never on Vds.

The Zener sits at about 90 uA with a 100k Rg, which is well below its knee, so it will clamp nearer 12-14 V than the marked 15 V. That is fine in both directions: the FET is fully enhanced past -10 V, and 14 V is comfortably inside the ±20 V limit. Drop Rg to 10k if a firmer clamp is wanted - it costs 8 mW and turns the FET on faster.

**Use the unidirectional TVS.** The `A` suffix is unidirectional, `CA` is bidirectional. This is a DC rail, and with the TVS sitting behind Q1 it never sees reverse voltage at all, so a bidirectional part only raises the clamp for nothing.

#### The TVS is chosen by the buck's absolute maximum, not by the rail

SMBJ26A stands off 26 V, breaks down between 28.9 and 31.9 V, and clamps at **42.1 V** at its 14.3 A peak pulse rating. The LM2675's absolute maximum supply voltage is **45 V**. That is the whole selection: 42.1 V fits under 45 V with a little room, and the next size up does not - SMBJ28A clamps at about 45.4 V and exceeds the regulator's rating outright.

**Be clear about what this does not protect.** The TMC2209 runs to 29 V with an absolute maximum near 30 V. Nothing can both stand off a 25.2 V rail (24 V nominal plus 5%) and clamp below 30 V under real fault current - the two requirements do not overlap. So for small and moderate transients the TVS conducts around 29-32 V and holds the drivers roughly in spec, while a large event clamps at 42 V and the drivers are what dies. The board and the supply survive; the sockets exist so that is a swap.

The practical mitigations are the ones already specified: **100 uF plus 100 nF at every driver socket**, so most of the motor's own energy is absorbed locally instead of travelling to the input TVS, and short motor leads. This is another instance of the design running a 24 V rail close to the TMC2209's ceiling, which is a known and accepted trade in this project.

#### Why the TVS goes behind the FET

Ahead of it, a reversed supply forward-biases the TVS into a dead short and blows F1 every time someone miswires. Behind the FET, reverse voltage never reaches it - and it still clamps motor transients, which originate on the load side anyway.

A 100 nF from gate to source slows turn-on into a controlled ramp if inrush into the bulk capacitor is tripping the fuse. Optional.

### I/O and safety

| Item | Qty | Notes |
|---|---|---|
| **E-stop** | 1 | **Hardware path that pulls all five driver EN high, independent of firmware.** Not a GPIO the software polls |
| Endstops | 5 | One per pump, NC microswitch or optical. See below |
| RUN switch | 1 | Maintained, as the current firmware expects |
| Pots | 0-2 | Optional once there is a web UI. **ADC1 pins only** - see gotcha below |
| Status LEDs | 3-5 | Power, run, fault |
| Display | 1 | On a header - see the display section below |
| I/O expander | 0 | Not needed on ESP32-S3. Required only on the classic-ESP32 fallback |
| Motor connectors | 5 | JST-XH 4-pin |
| Endstop connectors | 5 | JST-XH 3-pin |

**Add the endstops.** The current firmware assumes plunger positions at boot and counts steps from there - it has no way to know where a plunger actually is, and a skipped step is silent permanent error. Five endstops let the system home on startup and turn the travel limit from an assumption into a measurement. This is the single biggest reliability gain available.

## Display

Put it on a header rather than soldering it down - it lets you change your mind about size, and a failed display never bricks the board.

| Option | Interface | Header | Cost | Verdict |
|---|---|---|---|---|
| 0.96" OLED SSD1306, 128x64 | I2C | 4-pin | ~$3 | Workable, but 8 lines of ~21 chars is tight for five pumps plus ratios |
| 1.3" OLED SH1106, 128x64 | I2C | 4-pin | ~$5 | Same pixels, easier to read across a bench |
| 2.42" OLED SSD1309, 128x64 | I2C | 4-pin | ~$12 | Same layout code, genuinely readable at arm's length |
| **2.4" TFT ILI9341, 240x320** | SPI | 9-pin | ~$8 | **Best fit.** Room for all five pumps, colour-codes state, still cheap |
| 1.54" IPS ST7789, 240x240 | SPI | 8-pin | ~$6 | Same code path, but ~2 mm text - readable up close, not across a bench |
| 20x4 character LCD | I2C | 4-pin | ~$8 | Very readable, but no graphics and an awkward aspect for this data |

For a bench instrument you glance at while doing something else, **the 2.4" colour TFT is the right call.** Five pump rows with names, uL/min, percentage and syringe volume is about 20 lines of text - which a 128x64 OLED can only show by paging, and paging is exactly what you do not want when checking a running experiment at a glance.

Fit **both headers** on the board. An I2C display header costs four pins that are already routed for the expander, and the SPI header costs five GPIO you will have spare once the expander is in place.

| Header | Pins | Availability |
|---|---|---|
| I2C display | 3.3 V, GND, SDA, SCL (4.7k pullups on board) | Both N16 and N16R8 |
| SPI display | 9-pin, in the ILI9341 module's own order: VCC, GND, CS, RESET, DC, SDI, SCK, LED, SDO. RESET gets its own RC, SDO is a No-Connect | **N16 only** - sits on GPIO35-37 |

Drive both at **3.3 V logic**. Most OLED modules are fine; check any ILI9341 module, as some carry 5 V level shifters and some do not.

Show on it what the serial telemetry already computes: state, the three output split percentages, and per pump the commanded uL/min with remaining or accumulated syringe volume. The data model is identical - only the renderer differs.

## Pin budget

On **ESP32-S3-WROOM-1-N16** everything fits directly, with headroom:

| Function | Pins |
|---|---|
| STEP x5 | 5 |
| DIR x5 | 5 |
| ENABLE, shared | 1 |
| TMC2209 UART, single-wire, 2 buses | 2 |
| SPI display | 5 |
| I2C (spare, sensors) | 2 |
| Endstops x5 | 5 |
| RUN switch, E-stop sense | 2 |
| Status LEDs | 3 |
| Pots x2 (ADC1, GPIO1-10) | 2 |
| **Total** | **32 of ~34** |

Swap the SPI display for I2C and it drops to 27, which is comfortable.

Two notes that apply either way:

- **Use single-wire UART for the TMC2209s.** TX and RX bridged through a 1k resistor means one GPIO per bus instead of two. Standard practice on 3D printer boards. A TMC2209 takes a 2-bit address from MS1/MS2, so one bus addresses four drivers and the fifth needs a second bus.
- **The E-stop is never a GPIO decision.** Firmware senses its state so the UI and display can report it; the actual cut is a hardware path to driver ENABLE with no software involvement.

### Fallback: classic ESP32 pin budget

Classic ESP32-WROOM has 19 output-capable GPIO plus 4 input-only (GPIO6-11 are flash, 34-39 are input-only, 0/2/12/15 are strapping). Motion alone takes 15, leaving 4 output-capable and 4 input-only - and the pots need ADC1 on GPIO32-39, colliding with the pins the endstops want.

That is why the classic part needs an **MCP23017 I2C expander** (~$1.50) to absorb the endstops, switches and LEDs. It works fine; it is simply a problem the S3 does not have.

## Unused pins on the schematic

Seven module GPIOs go unused by this design. They do not all get the same treatment.

| Pin | Handling |
|---|---|
| **GPIO0** | **Not a No-Connect.** 10k pullup to 3V3 plus a button to GND - it is the boot strap, and NC-ing it means no download mode |
| GPIO3 | No-Connect. JTAG source select; floating is fine |
| GPIO43, 44 | **Not a No-Connect.** UART0 TX/RX, brought to the J-DBG header. Left unpopulated, but the pads are the serial recovery path if native USB ever fails |
| GPIO35, 36, 37 | See below - this is a decision, not a default |

KiCad's No-Connect flag is an ERC annotation, not a physical statement. It creates no copper and no net; it only suppresses the "pin not connected" warning so real omissions still surface.

### GPIO35/36/37: the variant decision

These are the only spare pins on an N16, and exactly the pins octal PSRAM claims on an R8. Three options:

| Approach | N16 | N16R8 | SPI display |
|---|---|---|---|
| No-Connect all three | Safe | Safe | **Foreclosed** |
| Route to the SPI display header | Works | **Hardware fault** | Available |
| **0 ohm series jumpers to the header** | Populate | Leave DNP | **Available on N16** |

**Do not route them and then fit an R8 module.** Those pads are bonded to the PSRAM die on that part, so external circuitry is bus contention rather than a merely wasted pin, and it can damage the module.

The series-jumper approach is the recommended one: three cheap parts turn the module variant into a BOM line instead of a board respin. Note that it means the pins are genuinely connected, so they get no NC flags - ERC reads the schematic, not the populate list.

## ESP32-S3 gotchas that must be designed around

**GPIO22-34 do not exist on the WROOM-1 module.** The pad numbering jumps straight from IO21 to IO35: 22-25 are absent from the die, 26-32 are bonded to the internal flash, and 33/34 are not brought out to the module at all. Assigning one produces a schematic net that goes nowhere and a board that is wrong in a way no DRC will catch. `config.h` carries a `PIN_EXISTS()` `static_assert` over every pin for this reason.

**ADC2 does not work while WiFi is active.** Silicon limitation on every ESP32 variant, not something firmware can route around - the pots read garbage the moment the radio comes up. On the S3, put them on **ADC1: GPIO1-10**. Ten channels, all normal bidirectional pins.

**GPIO26-32 are the SPI flash.** Unusable.

**GPIO35-37 are only free on the non-PSRAM part.** Octal PSRAM consumes them, which is why the SPI display header is N16-only and goes through 0R jumpers.

**GPIO19 and GPIO20 are native USB D- and D+.** Reserve them; that is what deletes the USB-serial chip.

**Strapping pins: GPIO0, GPIO3, GPIO45, GPIO46.** Anything pulled the wrong way at reset stops the board booting. Keep them off driver ENABLE, which is precisely the kind of net that sits at a defined level at power-up.

GPIO45 and GPIO46 carry the status LEDs, which is the one load that suits a strapping pin: anode-driven through 1k to ground, so the pin is hi-Z at reset and the internal pulldown puts both straps in the state they already need - 45 low for a 3.3 V VDD_SPI flash, 46 low for ROM message printing. An LED cannot pull either pin high. See `hardware/CONNECTIONS.md` for the full argument.

**No input-only pins.** Unlike classic ESP32's GPIO34-39, every S3 GPIO is bidirectional. This is a real simplification for endstop and LED placement.

**Antenna keepout.** The WROOM module's antenna end must overhang the board edge with no copper - no ground pour, no traces, on any layer.

For the classic-ESP32 fallback the equivalents shift: flash is GPIO6-11, GPIO34-39 are input-only, ADC1 is GPIO32-39, and the strapping pins are GPIO0, 2, 12, 15.

## Layout notes

The hard part of this board is that 24 V chopper currents and a 12-bit ADC share it.

- **Separate the power and signal grounds**, joined at exactly one point near the input capacitor.
- **Keep motor connector traces away from analog and step/dir lines.** The chopper switches at tens of kHz into an inductive load and radiates well.
- **Per-driver bulk capacitance close to the VM pin**, short and fat traces. This is the most common cause of driver death.
- **Thermal vias under each driver's exposed pad.** TMC2209s throttle when hot.
- 4-layer if the budget allows: signal / ground / power / signal. It solves most of the above by itself.

## Firmware implications

Moving to this board changes three things in the current code:

1. **Step generation** switches from AccelStepper polling to FastAccelStepper on hardware peripherals. All the latency mitigation in the current sketch - non-blocking telemetry, round-robin `analogRead` - becomes unnecessary. Keep the flow math and the state machine exactly as they are.
2. **Per-pump syringe geometry** stops being optional. `SYRINGE_ID_MM` and `SYRINGE_VOLUME_UL` are global today; with a web UI they become per-pump fields, which is also what a 15:1 input ratio needs to give both inputs a sensible barrel life.
3. **Homing** replaces the "load the syringes and trust the assumption" startup, once the endstops exist.

## Web interface

The ESP32 hosts this itself. No Pi, no external server.

### Resource reality check

| Resource | Available | Needed |
|---|---|---|
| Flash | 16 MB (`-N16` part) | ~200 KB for a single-page UI in LittleFS |
| SRAM | 520 KB, roughly 300 KB usable heap | ~50 KB for WiFi + async server |
| Concurrent clients | Several | 1-3 |

A pump interface is a handful of numbers and a couple of sliders. This is not a demanding workload - the ESP32 is over-specified for it, which is the position you want to be in.

### Stack

| Layer | Choice |
|---|---|
| HTTP/WebSocket | ESPAsyncWebServer (use the actively maintained **ESP32Async** fork, not the original me-no-dev repo) + AsyncTCP. `PsychicHttp` is a good alternative built on the ESP-IDF server |
| Live telemetry | WebSocket push at 1 Hz - the same cadence the serial telemetry uses now |
| Control | REST `POST` for setpoints, so a dropped socket cannot leave a command half-applied |
| UI assets | LittleFS. Small single-page app; no CDN, no framework needed |
| Discovery | mDNS - answers at `ufluidics.local` |
| Settings | NVS via `Preferences` - syringe geometry, flow constants, calibration |

### Pin the motion task to core 1

The ESP32 has two cores, and the Arduino core puts the WiFi/TCP stack on core 0.
Create the control task with `xTaskCreatePinnedToCore(..., 1)` so rate recomputation never waits behind network work.

Step generation is already immune - it runs on MCPWM/RMT hardware - but the control loop is ordinary code and should not share a core with the radio.

### Keep the web UI out of the safety path

This is the part that matters for an instrument.

- **Arm/disarm stays a physical switch.** A browser tab is not an interlock.
- **E-stop stays hardware**, cutting driver ENABLE with no firmware involvement.
- **Decide what a WiFi dropout means** and implement it deliberately. Continuing at the last commanded rate is usually right for a running experiment; stopping mid-run may waste the sample. Either is defensible - silently doing whichever falls out of the code is not.
- **A client disconnect must never stall the step generator.** With hardware stepping and a pinned control task, it cannot.

### Access control

Default HTTP has no authentication, which means **anyone on the same network can change your flow rates mid-experiment**.

Two reasonable answers:

- **AP mode with a WPA2 password.** The board makes its own network. Best for an instrument - no dependency on lab WiFi, no captive portal, no IT involvement. Connect a phone or laptop directly.
- **STA mode with HTTP basic auth**, if it must live on the lab network for remote monitoring.

Supporting both, with STA attempted first and AP as fallback, is about twenty lines and worth it - lab networks are frequently locked down in ways you find out about on demo day.

## Cost estimate

| Block | Approx |
|---|---|
| ESP32-S3-WROOM-1-N16 | $4 |
| 5x TMC2209 modules | $25 |
| Power stage (buck, LDO, protection, caps) | $12 |
| Connectors, switches, LEDs | $15 |
| 2.4" TFT display | $8 |
| PCB, 4-layer, small qty | $30 |
| **Board total** | **~$90** |
| 24 V 5 A PSU | $25 |
| 5x NEMA17 | $60 |

Excludes mechanics, syringes, and enclosure.

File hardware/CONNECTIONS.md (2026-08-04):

# ufluidics - connection reference

Net-by-net wiring for the ESP32-S3 board. Every MCU pin here is derived from `firmware/include/config.h` - if you change a pin there, change it here, and vice versa. The `static_assert`s in that file will catch a pin that does not exist on the module, but nothing will catch this document drifting out of date.

This file describes the intended design. For where the schematic currently departs from it, see [OPEN-ISSUES.md](OPEN-ISSUES.md).

Reference designators used below:

| Ref | Part |
|---|---|
| U1 | ESP32-S3-WROOM-1 |
| U2-U6 | TMC2209, one per pump: U2=IN1, U3=IN2, U4=OUT1, U5=OUT2, U6=OUT3 |
| U7 | 24 V -> 5 V buck (40 V+ rated) |
| U8 | 5 V -> 3.3 V LDO |
| J1 | 24 V input, 2-pin screw terminal |
| J2 | USB-C |
| J-M1..M5 | Motor outputs, JST-XH 4-pin |
| J-ES1..ES5 | Endstops, JST-XH 3-pin |
| J-POT-A/B | Potentiometers, JST-XH 3-pin |
| J-RUN | RUN switch, JST-XH 2-pin |
| J-ESTOP | E-stop, JST-XH 4-pin |
| J-DISP | I2C display, 4-pin |
| J-TFT | SPI display, 9-pin (N16 only) |
| J-DBG | UART0 serial console, 3-pin 0.1 in header |
| D-RUN / D-FAULT / D-PWR | Status LEDs, 0805 |

---

## U1 - ESP32-S3-WROOM-1

| Pad | Net | Function | Connects to | Dir |
|---|---|---|---|---|
| 1, 40, 41 | GND | Ground | Ground plane. **Pad 41 is the EPAD** - thermal vias | - |
| 2 | +3V3 | Logic supply | 3.3 V rail, 22 uF + 100 nF at the pad | - |
| 3 | ~RESET | Chip enable | 10k to 3V3, **1 uF** to GND, SW-RST to GND | in |
| 4 | GPIO4 | DIR IN1 | U2 TMC2209 DIR | out |
| 5 | GPIO5 | DIR IN2 | U3 TMC2209 DIR | out |
| 6 | GPIO6 | DIR OUT1 | U4 TMC2209 DIR | out |
| 7 | GPIO7 | DIR OUT2 | U5 TMC2209 DIR | out |
| 8 | GPIO15 | DIR OUT3 | U6 TMC2209 DIR | out |
| 9 | GPIO16 | DRV_EN (all 5) | U2-U6 TMC2209 EN, via E-stop | out |
| 10 | GPIO17 | TMC_UART_A | U2-U5 PDN_UART pin 4 (1k on module) | bidir |
| 11 | GPIO18 | TMC_UART_B | U6 PDN_UART pin 4 (1k on module) | bidir |
| 12 | GPIO8 | ENDSTOP IN1 | J-ES1 pin 2 | in, pullup |
| 13 | GPIO19 | USB_D- | USB-C D- (CC 5k1 each) | bidir |
| 14 | GPIO20 | USB_D+ | USB-C D+ | bidir |
| 15 | GPIO3 | LED_RUN | D-RUN anode, 1k | out |
| 16 | GPIO46 | LED_FAULT | D-FAULT anode, 1k | out |
| 17 | GPIO9 | ENDSTOP IN2 | J-ES2 pin 2 | in, pullup |
| 18 | GPIO10 | ENDSTOP OUT1 | J-ES3 pin 2 | in, pullup |
| 19 | GPIO11 | ENDSTOP OUT2 | J-ES4 pin 2 | in, pullup |
| 20 | GPIO12 | ENDSTOP OUT3 | J-ES5 pin 2 | in, pullup |
| 21 | GPIO13 | RUN switch | J-RUN pin 2 | in, pullup |
| 22 | GPIO14 | ESTOP_SENSE | E-stop aux contact | in, pullup |
| 23 | GPIO21 | I2C_SCL | J-DISP pin 4, 4k7 to 3V3 | bidir |
| 24 | GPIO47 | I2C_SDA | J-DISP pin 3, 4k7 to 3V3 | bidir |
| 25 | GPIO48 | TFT_DC | J-TFT pin 6 | out |
| 26 | GPIO45 | unused | No-Connect | - |
| 27 | GPIO0 | BOOT strap | 10k to 3V3 + SW-BOOT to GND | in |
| 28 | GPIO35 | TFT_SCK  (N16 only) | J-TFT pin 3, via 0R jumper | out |
| 29 | GPIO36 | TFT_MOSI (N16 only) | J-TFT pin 4, via 0R jumper | out |
| 30 | GPIO37 | TFT_CS (N16 only) | J-TFT pin 5, via 0R jumper | out |
| 31 | GPIO38 | STEP IN1 | U2 TMC2209 STEP | out |
| 32 | GPIO39 | STEP IN2 | U3 TMC2209 STEP | out |
| 33 | GPIO40 | STEP OUT1 | U4 TMC2209 STEP | out |
| 34 | GPIO41 | STEP OUT2 | U5 TMC2209 STEP | out |
| 35 | GPIO42 | STEP OUT3 | U6 TMC2209 STEP | out |
| 36 | GPIO44 | UART0_RX (spare) | J-DBG pin 3 | in |
| 37 | GPIO43 | UART0_TX (spare) | J-DBG pin 2 | out |
| 38 | GPIO2 | POT_B (ADC1_CH1) | J-POT-B wiper | analog in |
| 39 | GPIO1 | POT_A (ADC1_CH0) | J-POT-A wiper | analog in |

Unlisted pads (GPIO22-34) do not exist on this module - the numbering jumps from IO21 to IO35.

**Pads 36 and 37 appear in the schematic as `RXD0` and `TXD0`, not as `IO44` and `IO43`.** KiCad's `RF_Module:ESP32-S3-WROOM-1` symbol names those two pins by their UART0 function, matching Espressif's own pinout table. They are the same pins: pad 36 = RXD0 = GPIO44, pad 37 = TXD0 = GPIO43. Every other pad is named `IOnn`, so these two are the only place where the symbol label and this table disagree on wording.

### Status LEDs - D-RUN, D-FAULT, D-PWR

All three are wired the same way: **anode toward the source, cathode to ground.**

```
  GPIO3  --[R 1k]--|>|-- GND      D-RUN, green
  GPIO46 --[R 1k]--|>|-- GND      D-FAULT, red
  +3V3   --[R 2k2]--|>|-- GND     D-PWR, green - always on, no GPIO
```

| Ref | Net | Series R | Current | Meaning |
|---|---|---|---|---|
| D-RUN | GPIO3 | 1k | ~1.2 mA | Solid = pumping |
| D-FAULT | GPIO46 | 1k | ~1.4 mA | Blinking = fault |
| D-PWR | +3V3 | 2k2 | ~0.6 mA | Rail is up |

At 3.3 V with a green Vf of about 2.1 V, 1k gives (3.3 - 2.1) / 1000 = 1.2 mA; a red Vf of 1.9 V gives 1.4 mA. That is dim by 1990s standards and perfectly visible on any modern high-efficiency part. Drop to 470R if the enclosure window is tinted - about 3 mA, still an order of magnitude under the 20 mA the ESP32-S3 wants as a per-pin ceiling, and still inside the 10 mA the power budget allots to indicators.

Put D-PWR on **+3V3**, not on +5V or +24V. A 3.3 V indicator proves the buck *and* the LDO are both alive, which is the question you actually have when a board does nothing.

**Do not wire these active-low.** The tempting alternative - 3V3 through the resistor to the LED, GPIO sinking to turn it on - would work on an ordinary pin and is wrong here: it holds GPIO3 and GPIO46 *high* through the resistor while the pin is hi-Z at reset. That is a mis-strapped JTAG source select and a mis-strapped boot log setting, on every power-up. The anode-to-GPIO topology is what makes these two pins usable at all.

Firmware matches: `digitalWrite(LED_RUN_PIN, HIGH)` lights it.

### Why the status LEDs sit on strapping pins

The indicator LEDs are on **GPIO3 and GPIO46**, both strapping pins, rather than on the UART0 pair. That is deliberate in both directions.

Putting the LEDs on strapping pins is safe because of how they are driven. Each LED is anode-driven through a 1k series resistor to ground, so the MCU pin sources current when the LED is lit and is high-impedance during reset. An LED wired this way can never pull its pin high, because its cathode is at ground - the worst it can do is offer a weak path to GND, which is the low state every strap here wants anyway. Firmware drives them long after the straps are latched, and any reset re-tristates the pin before the next sample.

GPIO46 has a documented internal pulldown at reset, so it reads 0 regardless - low leaves ROM message printing enabled. GPIO3 selects JTAG signal source (0 = USB-JTAG, 1 = external JTAG pins); Espressif does not document an internal pulldown on this pin the way it does for 45/46, so the LED's resistor-to-GND path is doing more of the work. It should still sample low - 0, USB-JTAG, the default this board wants since debugging goes over native USB - but **this was moved here for routing convenience and has not been bench-verified.** Check it with a meter or scope on first power-up. If it ever sampled high, the consequence is USB-JTAG being deselected in favor of external JTAG pins this board does not expose - inconvenient, not boot-breaking.

GPIO45 (the original home of LED_RUN, VDD_SPI strap) is unpopulated now - No-Connect, per the pin table.

Keeping the LEDs *off* GPIO43/44 buys two things:

- **A serial recovery port.** The console normally runs over native USB (GPIO19/20). If that is ever unusable - a bad USB descriptor, a bricked CDC config, a bootloader problem - UART0 on a 3-pin header is the way back in. Spending it on an LED removes the only fallback.
- **No boot flicker.** The ROM bootloader prints its log on TXD0 at every reset. An indicator LED on that pin flashes on every power-up, which reads as a fault to anyone watching the panel.

Bring GPIO43/44 out to **J-DBG**, a 3-pin 0.1 in header: pin 1 GND, pin 2 TX, pin 3 RX. No population cost if left unstuffed.

**No external crystal or oscillator.** The 40 MHz crystal, its load capacitors, the SPI flash and the RF matching network are all inside the module - that is the main thing you are buying over a bare ESP32-S3 chip. Nothing external is needed beyond the reset RC, the boot strap and decoupling.

A 32.768 kHz crystal is optional on ESP32-S3 for RTC accuracy in deep sleep, and is not wanted here: this system runs continuously, and its pins (XTAL_32K_P/N = GPIO15/16) already carry DIR OUT3 and DRV_EN. The internal 40 MHz reference is typically +/-10 ppm, which is four orders of magnitude below the syringe-bore uncertainty that dominates volumetric error.

**Antenna keepout:** the module's antenna end must overhang the board edge with no copper on any layer.

---

## U2-U6 - TMC2209 stepper drivers

Identical wiring except for STEP, DIR and the UART address straps.

### Common to all five

Two very different parts share the name TMC2209. A **SilentStepStick-style module** carries the charge pump, sense resistors and regulator caps on board, so it needs almost nothing external. A **bare QFN-28** needs all of that from you.

The pin names decide which you have: if your symbol shows `VS`, `VCP`, `CPI`, `CPO`, `5VOUT`, `BRA` and `BRB`, it is the bare IC.

#### SilentStepStick-style module (socketed - what this board uses)

| Module pin | Connects to | Notes |
|---|---|---|
| VMOT | +24 V | 100 uF electrolytic + 100 nF at the module |
| GND | Ground plane | |
| VIO / VDD | **+3.3 V** | Logic reference, not the operating supply - see below |
| EN | DRV_EN net | Active LOW |
| STEP, DIR | Hierarchical sheet pins | |
| PDN_UART | Bus, directly (BTT) | BTT Pin 4; the 1k is on the module. Pin 5 stays NC |
| MS1, MS2 | Strapped per instance | |
| VREF | No-Connect | The onboard trimpot already drives it |
| DIAG, INDEX | No-Connect | Optional |
| 1A, 1B / 2A, 2B | J-Mx | Motor coils |

Charge pump, sense resistors and regulator capacitors are all on the module - roughly forty passives that do not appear on this board's BOM. Still fit **100 uF electrolytic + 100 nF per socket** on VMOT: the module's own decoupling is small, and the socket adds inductance between it and the bulk capacitor.

Footprint: the standard 2x8 0.1 in StepStick outline, `Module:Pololu_Breakout-16_15.2x20.3mm` in the KiCad library. Use female headers so a failed driver is a swap rather than a rework.

**Pin order differs between Watterott, BigTreeTech and FYSETC** even though all three claim the A4988 footprint. Once you socket them, the board is committed to whichever pinout you route - pick the exact part first and wire by signal name against its datasheet.

##### As-wired socket pinout - verified, do not re-derive

This is what the schematic routes, checked against the module and confirmed correct. Both rows are `Connector_Generic:Conn_01x08`. Reviewers have twice tried to re-derive this from the generic StepStick order and reached the wrong answer; the table below is the authority.

| Pin | Logic row (J1, J4, J7, J10, J13) | Power row (J2, J5, J8, J11, J14) |
|---|---|---|
| 1 | EN -> `DRIVER_EN` | GND |
| 2 | MS1 -> strapped, see address table | VIO -> **+3V3** |
| 3 | MS2 -> strapped, see address table | 1B |
| 4 | PDN_UART -> `TMC_UART_A` / `TMC_UART_B` | 1A |
| 5 | Alternate PDN pad - **No-Connect** | 2A |
| 6 | CLK -> GND | 2B |
| 7 | STEP | GND |
| 8 | DIR | VMOT -> **+24V** |

Two points that look like mistakes and are not:

- **Power row pin 1 is GND and pin 2 is VIO**, not the other way round. The generic StepStick order puts VDD on the end pin; this module does not.
- **Logic row pin 5 is No-Connect.** See the PDN section above - it is the alternate position for the same single-wire line, not a second UART pin.

UART addresses, set by the MS1/MS2 straps:

| Socket | Bus | MS1 (pin 2) | MS2 (pin 3) | Address |
|---|---|---|---|---|
| J1 | `TMC_UART_A` -> GPIO17 | GND | GND | 0 |
| J4 | `TMC_UART_A` | +3V3 | GND | 1 |
| J7 | `TMC_UART_A` | GND | +3V3 | 2 |
| J10 | `TMC_UART_A` | +3V3 | +3V3 | 3 |
| J13 | `TMC_UART_B` -> GPIO18 | GND | GND | 0 |

Four addresses is the TMC2209's limit per bus, which is why the fifth driver gets its own pin.

##### Two PDN pads (BigTreeTech TMC2209 V1.2/V1.3)

The two pads are **not** TX and RX. They are two alternative positions for the same single-wire PDN_UART line, and an on-board 1k resistor selects which one is live.

From BigTreeTech's own documentation: *"The factory has connected the UART Pin to the fourth Pin, namely the PDN_UART Pin... If the fifth Pin is used as the UART Pin, the resistance shall be removed and welded to the following two pads."*

| Pad | Wiring |
|---|---|
| **Pin 4** (PDN_UART) | To the UART bus. Factory default, nothing to modify |
| **Pin 5** | **No-Connect** - physically open on the module unless you relocate the resistor |

**Do not add an external 1k series resistor.** BigTreeTech already fitted it; another in series makes 2k. This differs from a bare TMC2209 or some other vendors' modules, where the resistor is the host board's job.

Klipper drives these with a single `uart_pin`, which confirms single-wire half-duplex operation - so one GPIO per bus is correct and the pin budget is unchanged.

> If you switch to a different vendor's module, re-check this. Watterott SilentStepSticks and bare ICs do **not** carry the resistor, and some modules genuinely do split TX and RX. An ohmmeter between the pads tells you which you have: ~0 ohm means duplicated pinout, ~1k means the resistor sits between them.

##### CLK

**CLK ties to GND**, selecting the internal ~12 MHz oscillator.

- Do not leave it floating. It is a clock input, and floating next to a 24 V chopper it will pick up switching noise and upset the chopper.
- Oscillator accuracy does not affect flow. Position comes entirely from STEP pulse count, which the DDS controls; CLK only sets chopper and StealthChop PWM frequency, so its tolerance is irrelevant here.
- Some modules ground CLK on-board and still expose the pad. Check yours - if so it is a No-Connect on your side.

##### VIO must be 3.3 V, and this is not a preference

VIO sets the driver's logic reference only; the chip runs from VM through its own regulator, so 3.3 V costs nothing.

At 5 V two things break in opposite directions:

- **Inbound:** the input-high threshold is roughly 0.7 x VIO, so 3.5 V at a 5 V VIO. The ESP32 drives 3.3 V, which lands below it. Missed STEP pulses with no error anywhere.
- **Outbound:** `PDN_UART` is bidirectional. The driver answers register reads at VIO, so a 5 V VIO drives 5 V into GPIO17/GPIO18. **The ESP32-S3 is not 5 V tolerant**, and both pins fan out to five drivers - one wrong rail damages the MCU on the first UART read.

Do not tie VIO to the module's `5VOUT` pin either, where one is exposed; that is the internal regulator and puts you in the same place. VIO draw is microamps to low milliamps, so five drivers are nothing for the 3.3 V LDO.

##### Two hazards the socket introduces

**A module inserted backwards is destroyed instantly**, and nothing stops it mechanically - both rows are 8 pins at the same pitch. Mitigate on silkscreen: outline the module body, mark pin 1, and label which end carries VMOT. A reversed driver puts 24 V onto the logic pins and can take the ESP32 with it.

**Never hot-plug a driver.** Removing or inserting one with VMOT live kills the output stage. Power down completely before swapping - which is the whole reason for sockets, so it is worth putting on the silkscreen too.

#### Bare TMC2209 (QFN-28) - reference only, not used on this board

| Pin | Connects to | Required? |
|---|---|---|
| VS | +24 V | **Yes.** This is the motor supply. 100 nF at the pin plus 100 uF electrolytic |
| VCP | **100 nF to VS** | **Yes.** Charge-pump buffer. Note it returns to VS, not GND |
| CPI, CPO | **22 nF between the two pins** | **Yes.** Charge-pump flying capacitor |
| 5VOUT | 2.2 uF X7R to GND | **Yes.** Internal LDO output; do not load it externally |
| VCC | 5VOUT, with its own 100 nF to GND | **Yes**, if your symbol breaks it out separately |
| VCC_IO | +3.3 V, 100 nF to GND | **Yes.** Sets the logic level. 3V3, not 5 V |
| BRA | Sense resistor to GND, 0.11 ohm 1% | **Yes.** Bridge A current sense |
| BRB | Sense resistor to GND, 0.11 ohm 1% | **Yes.** Bridge B current sense |
| VREF | VCC_IO | **Yes.** Analog input, must not float. IRUN scales from it in UART mode |
| OA1, OA2 | J-Mx pins 1, 2 | Motor coil A |
| OB1, OB2 | J-Mx pins 3, 4 | Motor coil B |
| EN (ENN) | DRV_EN net, active LOW | |
| STEP, DIR | Hierarchical sheet pins | |
| PDN_UART | Bus, directly (BTT) | BTT Pin 4; the 1k is on the module. Pin 5 stays NC |
| MS1, MS2 | Strapped per instance - see the address table | |
| SPREAD | GND | StealthChop |
| CLK | GND | Selects the internal oscillator. Never leave floating |
| DIAG | No-Connect, or a spare GPIO for StallGuard | Optional |
| INDEX | No-Connect | Optional |
| NC | No-Connect | |
| GND, exposed pad | Ground plane | **Yes.** Solder the EPAD with thermal vias - it is the only heat path |

Leaving VS, VCP, CPI/CPO or 5VOUT open means the part does not run at all: the charge pump generates the high-side gate drive. Leaving BRA/BRB open means no current sense, which is worse than not running.

**Per-driver passive count, bare IC:** 2x 0.11 ohm sense, 22 nF, 2x 100 nF, 2.2 uF, 100 nF, plus 100 nF + 100 uF on VS. About eight parts each, forty across the board. That is the real cost of bare ICs over modules - the silicon is cheaper, the BOM line count is not.

Sense resistor value sets the current ceiling: 0.11 ohm gives roughly 1.4 A RMS at full scale, which is what makes the 800 mA in `TMC_RMS_CURRENT_MA` a comfortable setting rather than a stretch.

### Per-driver

| Ref | Pump | STEP from | DIR from | PDN_UART | MS1 | MS2 | Addr |
|---|---|---|---|---|---|---|---|
| U2 | IN1 | GPIO38 | GPIO4 | TMC_UART_A (GPIO17) | GND | GND | 0 |
| U3 | IN2 | GPIO39 | GPIO5 | TMC_UART_A | VIO | GND | 1 |
| U4 | OUT1 | GPIO40 | GPIO6 | TMC_UART_A | GND | VIO | 2 |
| U5 | OUT2 | GPIO41 | GPIO7 | TMC_UART_A | VIO | VIO | 3 |
| U6 | OUT3 | GPIO42 | GPIO15 | TMC_UART_B (GPIO18) | GND | GND | 0 |

**On BigTreeTech modules the 1k series resistor is already fitted** - wire Pin 4 straight to the bus and add nothing. Bare ICs and some other vendors' modules need an external 1k per driver. See the two-pad note above.

A TMC2209 takes only a 2-bit address, so one bus reaches four drivers. That is the entire reason for the second bus - U6 is alone on it and can keep address 0.

**MS1/MS2 are not microstepping select.** That is their standalone-mode role. Once PDN_UART is used for UART they become the address, and microstepping moves to `CHOPCONF.MRES` in software. So the four drivers on bus A must be strapped *differently* - identical straps collide the bus.

**`VIO` in that table means the +3V3 rail** - the same net that feeds the module's VIO/VDD pin, nothing else. Not +5V, not VMOT, and not the module's `5VOUT` pad. A logic input above VIO is out of spec, and the reason VIO is 3.3 V in the first place is the section above.

MS1 and MS2 have internal pull-downs, so a pin strapped to GND could in principle be left open. **Strap it anyway.** These are high-impedance inputs a few millimetres from a 24 V chopper, the same argument that grounds CLK, and a floating pin records no intent - the next person cannot tell address 0 from a forgotten net. Some vendors' modules also add their own pull-ups, which silently inverts the table.

Route each strap through its own **solder jumper or 0R pad to +3V3 and to GND**. The drivers are socketed and interchangeable, so the address lives on this board, not on the module - and a reworkable pad is the difference between changing an address and cutting a trace. Current through a strap is the pull-down's, tens of microamps, so the pads carry nothing.

**Maximum resolution does not come from these pins.** The firmware commands 1/16 and enables MicroPlyer, which interpolates to 256 microsteps inside the driver: the motor sees 1/256 motion while the step rate stays at 181 steps/s peak. Commanding 1/256 natively would give identical smoothness at 2894 steps/s - 16x the interrupt load and EMI for nothing. Interpolation is also at its best here, since MicroPlyer predicts from the last step interval and this system only ever runs at constant velocity.

> **Verify the UART config at startup.** `CHOPCONF.MRES` resets to 0, which is 256 microsteps. A driver that never received its configuration therefore runs at 1/256 while the firmware sends 1/16-rate pulses, delivering **16x too little flow** with nothing reporting a fault. A mis-strapped address does this. Check `test_connection()` on every driver and fault the system if any does not answer.

> **Validate the single-wire UART early.** One GPIO per bus relies on the ESP32 GPIO matrix mapping both U*TXD and U*RXD onto the same pad. It is used successfully in ESP32 Marlin builds, but prove it on a devkit before committing copper. If it does not behave, the fallback is separate TX and RX per bus - two extra pins, which N16 has spare and **R8 does not**.

---

## Power

```
J18 (24 V) --[F1 2A T]--[Q1 P-FET]--+-- +24V
                                    |
              D6 TVS SMBJ26A -------+
              C9 470 uF 35 V --------+
                                    |
                    +---------------+---------------+
                    |                               |
      driver VMOT (5x sockets)          U5 buck 24 -> 5 V
                                                    |
                                                +5V rail
                                                    |
                                        U3 LDO 5 -> 3.3 V
                                                    |
                            +3V3: U1, all VIO, pots, display
```

| Net | Sources | Loads |
|---|---|---|
| +24V | J18 via F1/Q1 | Driver VMOT x5, U5 VIN |
| +5V | U5 | U3 input, VBUS Schottky D1 |
| +3V3 | U3 | U1 (22 uF + 100 nF at pad 2), all driver VIO, pot high side, display |

### Input protection, net by net

Refdes match the schematic. D1 and D2 were already the VBUS Schottky and the buck catch diode, so the protection parts start at D6.

| Ref | Value | Pin | Net |
|---|---|---|---|
| J18 | Screw terminal 2-pin | 1 | GND |
| | | 2 | `VIN_RAW` |
| F1 | 2 A time-lag, 5x20 holder | 1 | `VIN_RAW` |
| | | 2 | `VIN_FUSED` |
| Q1 | P-channel, >= -60 V | **D (drain)** | `VIN_FUSED` |
| | | **S (source)** | `+24V` |
| | | **G (gate)** | `Q1_GATE` |
| R11 | 100k | 1 | `Q1_GATE` |
| | | 2 | GND |
| D7 | 15 V Zener, BZV55C15 | **A (anode)** | `Q1_GATE` |
| | | **K (cathode)** | `+24V` |
| D6 | TVS SMBJ26A | **cathode / pad 1** | `+24V` |
| | | **anode / pad 2** | GND |
| C9 | 470-1000 uF, 35 V, low ESR | + | `+24V` |
| | | - | GND |

Three nets are new: `VIN_RAW`, `VIN_FUSED`, `Q1_GATE`. Everything already on `+24V` - U5 pin 7, the five socket VMOT pins, `Cin`/`Cin1`/`Cin2`/`Cinx` - stays where it is and simply ends up downstream of the protection.

**The one edit to existing wiring:** J18 pin 2 currently connects straight to `+24V`. Break that and relabel it `VIN_RAW`. If you miss this the whole block is shorted out and does nothing, while the board still works perfectly on the bench - which is the worst possible failure to ship.

Watch three orientations, because all three are silently wrong rather than obviously wrong:

- **Q1 drain faces the input, source faces the load.** Reversed, the body diode conducts a backwards supply straight through the board.
- **D7 cathode to source**, anode to gate. Reversed it is a forward diode clamping the gate 0.7 V below the rail and the FET never turns on.
- **D6 cathode to +24V**, anode to GND. Reversed it is a forward diode across the supply and blows F1 on first power-up. Watch this one: KiCad's `Diode:SM6T*` symbols name both pins `A1`/`A2` even though the parts are unidirectional, so the schematic shows no cathode. `Diode_SMD:D_SMB` puts the band on **pad 1**, which makes pin 1 the end that goes to `+24V`.
- **D6 belongs on the rail, not on the gate.** Wired gate-to-GND it never conducts, nothing looks wrong on the bench, and the rail has no protection at all.

Keep the return unfused: J18 pin 1 straight to the ground plane.

The per-socket **100 uF + 100 nF on VMOT** hang off `+24V` at each driver, not at the input. That placement is the point - the socket's inductance is what makes a distant bulk capacitor useless to the driver.

#### Bench check before trusting it

1. No load, correct polarity: `+24V` should read within a few tens of millivolts of `VIN_FUSED`. A 0.6 V drop means Q1 never enhanced and current is going through the body diode - check D7's orientation.
2. Reverse the supply leads deliberately, current-limited: `+24V` should read 0 V and the fuse should survive.
3. Measure `Q1_GATE` in normal operation. Expect roughly 10-12 V below `+24V`. Near 0 V difference means the Zener is backwards or R11 is open.
| GND | - | Single-point join between power and signal ground near C1 |

**Never linear-regulate 3.3 V from 24 V.** At the ESP32's 500 mA WiFi peak that dissipates 10.4 W. The intermediate 5 V rail exists for exactly this reason.

---

## Connectors

### J-M1..M5 - motors (JST-XH 4-pin)

| Pin | Net |
|---|---|
| 1 | Coil A+ (driver 1A) |
| 2 | Coil A- (driver 1B) |
| 3 | Coil B+ (driver 2A) |
| 4 | Coil B- (driver 2B) |

Never hot-plug a stepper into a powered driver.

### J-ES1..ES5 - endstops (JST-XH 3-pin)

| Pin | Net |
|---|---|
| 1 | GND |
| 2 | Signal -> U1 GPIO8/9/10/11/12 |
| 3 | +3V3 |

Use normally-closed switches so a broken wire reads as triggered. Internal pullups are enabled in firmware; no external resistor needed.

### J-POT-A / J-POT-B (JST-XH 3-pin)

| Pin | Net |
|---|---|
| 1 | +3V3 |
| 2 | Wiper -> U1 GPIO1 / GPIO2, **100 nF to GND at the board** |
| 3 | GND |

**Pot low side goes to GND, never to AREF.** These are ratiometric against the 3.3 V rail, so supply droop cancels out. Return the pot ground near the analog section, not to the driver power ground - motor return current through a shared path shows up as split drift under load.

### J-RUN (2-pin) and J-ESTOP (4-pin)

| Connector | Pin | Net |
|---|---|---|
| J-RUN | 1 | GND |
| J-RUN | 2 | U1 GPIO13, internal pullup. Maintained switch, closed = run |
| J-ESTOP | 1, 2 | **NC contact in series with the DRV_EN net.** Hardware path, no firmware |
| J-ESTOP | 3 | Aux contact -> U1 GPIO14 (sense only, for the UI) |
| J-ESTOP | 4 | GND |

The E-stop must break DRV_EN in hardware. GPIO14 exists only so the display and web UI can report the state - it is not the interlock.

**Breaking the wire is not sufficient - the pull-up is what makes it work.**

```
  GPIO16 ----[ J-ESTOP pins 1-2, NC contact ]----+---- DRV_EN -> 5x driver EN
                                                 |
                                             [10k] to +3V3
```

TMC2209 EN is active LOW. An open net floats, and a floating EN input may read as enabled - so a bare series contact can leave the drivers live. The 10k to VIO is what turns an open contact into a defined *disabled*. Use a latching mushroom head with **NC** contacts so a cut cable also reads as tripped.

Holding torque disappears when EN goes high. That is acceptable here: a 2 mm lead screw is not back-drivable, so line pressure cannot push a plunger back.

**The RUN switch does not replace this.** GPIO13 is an input firmware polls; stopping depends on firmware running, the ISR being alive and the main loop being reached. The E-stop exists for the case where none of that is true - a hung ISR, a watchdog that did not fire, a crash that left STEP toggling. In that state the RUN switch is an input nobody is reading, and a syringe pump keeps driving a plunger into a closed line.

### J-DISP - I2C display (4-pin, works on N16 and R8)

| Pin | Net |
|---|---|
| 1 | +3V3 |
| 2 | GND |
| 3 | SDA -> U1 GPIO47, 4k7 pullup to 3V3 |
| 4 | SCL -> U1 GPIO21, 4k7 pullup to 3V3 |

### J-TFT - SPI display (9-pin, **N16 only**)

Pin order matches the 2.4" ILI9341 module exactly, so the cable is straight-through with no crossed conductors.

| Pin | Module label | Net |
|---|---|---|
| 1 | VCC | +3V3 |
| 2 | GND | GND |
| 3 | CS | GPIO37, **via 0R jumper R-J3** |
| 4 | RESET | Own RC: 10k to +3V3, 100 nF to GND. **Not the MCU ~RESET net** |
| 5 | DC | GPIO48 |
| 6 | SDI (MOSI) | GPIO36, **via 0R jumper R-J2** |
| 7 | SCK | GPIO35, **via 0R jumper R-J1** |
| 8 | LED | +3V3 through solder jumper R-BL |
| 9 | SDO (MISO) | **No-Connect** |

**Leave R-J1..R-J3 unpopulated when fitting an N16R8 module.** GPIO35/36/37 are bonded to the PSRAM die on that part, and driving them is bus contention, not a wasted pin.

Three things to check on the specific module before wiring it:

- **VCC voltage.** Modules carrying an AMS1117 and a level shifter accept 5 V; bare ones are 3.3 V only. This header supplies 3.3 V, which is safe for both - an AMS1117 part simply runs in dropout on its regulator and takes logic level directly. Never move this pin to 5 V to "help" a regulated module: the logic pins on a bare module are not 5 V tolerant, and you cannot tell the two apart from the connector.
- **SDO is left open deliberately.** The firmware never reads registers back, and nothing else shares this SPI bus, so a module whose SDO does not tri-tri-state properly cannot cause trouble. If you later add a second SPI device, revisit this.
- **Touch, if the module has it.** Many 2.4" ILI9341 boards add an XPT2046 with T_CLK, T_CS, T_DIN, T_DO and T_IRQ. Those stay unconnected: touch would want five more GPIO plus a second CS, and there is no room in the pin budget. The pots and the web UI are the input path.

##### RST gets its own RC, not the MCU reset net

Sharing the board's ~RESET net looks free and costs nothing in GPIO, but it loads the one node on this board whose time constant was chosen deliberately. EN carries 10k and 1 uF for a ~10 ms power-up delay. Most ILI9341 modules already fit their own pull-up on RST, typically 10k to their 3.3 V; tie the two together and that pull-up lands in parallel with the board's, halving R and halving the EN delay. The EN cap was sized to 1 uF for a reason, and this quietly undoes it.

Give the display its own **10k to +3V3 and 100 nF to GND** instead. That is a ~1 ms low pulse at power-up, comfortably past the 10 us minimum the controller asks for, and it is independent of anything the MCU does.

Losing the shared reset costs nothing in practice: every driver library issues a software reset (`SWRESET`, 0x01) during init, so a display that missed a hardware reset still comes up clean when firmware restarts. The hardware pulse only has to cover the power-up case, which is exactly what the RC does.

If the module turns out to have no pull-up of its own, tying RST to the MCU ~RESET net becomes safe again - but check with an ohmmeter before assuming it, not after.

##### LED / BL is a backlight, not a logic pin

The backlight is four white LEDs and it dominates the module's draw - roughly **60-100 mA** on a 2.4" panel against the 80 mA this design budgets for the display as a whole. It is worth measuring on your actual module rather than trusting a listing. Two consequences:

- **Never drive it from a GPIO directly** unless the pin is a transistor base. 60 mA is three times the ESP32-S3's 20 mA per-pin ceiling; the pin survives at first and degrades.
- **Check what the pin actually is before connecting it.** An ohmmeter from the pin to GND tells you: a few hundred ohms means a series resistor is fitted, open means it is a logic input to an on-board driver, near-zero means a bare LED anode and the resistor is your job.

Simplest correct wiring is **the LED pin to +3V3, backlight always on**, which is what a bench instrument wants anyway. Wire it as a **2-pad solder jumper to +3V3, strapped by default** (R-BL), with the free side stubbed to a spare GPIO pad. Dimming then costs a jumper move rather than a respin.

Which pin drives it depends on which of the three types you have:

- **Logic input to an on-board driver** (the common case on modules whose documentation says "connect to a GPIO"): strap to +3V3 for always-on, or drive the pin directly and PWM it with LEDC. No external transistor - the module already has one. **Check polarity first**: some modules switch a PNP or P-FET, so LOW is on, and strapping that kind to +3V3 gives a dark screen that reads as a dead display.
- **LED anode with a series resistor on-board:** +3V3 only. A GPIO cannot sink or source this.
- **Bare LED anode:** you supply the series resistor, then +3V3.

For the last two, dimming needs a low-side N-channel FET (2N7002 or similar): BL to +3V3, LED return through the FET drain, source to GND, gate to a GPIO with a **100k pull-up to +3V3** so the backlight defaults ON if firmware never touches it. Nothing on this board is worth a dark screen because a pin failed to initialize.

Either way the backlight current comes from the module's VCC pin - J-TFT pin 1, off the 3.3 V rail, through the LDO. Switching it with a GPIO gates that current; it does not move it somewhere cheaper.

There is no spare GPIO for backlight control today: GPIO43/44 are the debug UART. Leave the pad and the jumper, populate when a pin frees up.

### J-DBG - UART0 console (3-pin 0.1 in header)

| Pin | Net |
|---|---|
| 1 | GND |
| 2 | UART0_TX -> GPIO43 (pad 37) |
| 3 | UART0_RX -> GPIO44 (pad 36) |

Unpopulated by default - the pads cost nothing and the header goes on only when it is needed. This is the recovery path when the native USB console is not available, and it is where the ROM bootloader prints at 115200 baud on every reset. Levels are 3.3 V; do not connect a 5 V adapter without a level shifter.

---

## USB-C (J2)

A 16-pin USB 2.0 receptacle is enough - the SBU and SS pairs of a 24-pin part go unused. Wired as a **device** (UFP), data only, no power delivery negotiation.

| Receptacle pin(s) | Net | Notes |
|---|---|---|
| A1, B1, A12, B12 | GND | All four to the plane |
| A4, B4, A9, B9 | VBUS | All four tied together |
| **A5** | **CC1** | **5.1k to GND - its own resistor** |
| **B5** | **CC2** | **5.1k to GND - its own resistor** |
| A6, B6 | D+ | Tie together, then to U1 GPIO20 |
| A7, B7 | D- | Tie together, then to U1 GPIO19 |
| A8, B8 | SBU1, SBU2 | No-Connect for USB 2.0 |

### The CC resistors are the classic mistake

**Each CC pin needs its own 5.1k pulldown.** One shared resistor across both is the single most common USB-C error, and it produces a port that works with some cables and hosts and not others - which reads as a flaky cable rather than a board fault.

The host uses CC1 and CC2 to detect plug orientation. Tie them together and orientation detection fails; many hosts then refuse to enumerate or never turn on VBUS. Two separate 5.1k (Rd) advertises "device, USB default current" and is correct for anything drawing 500 mA or less.

### D+ and D- tie together, deliberately

A USB-C receptacle carries the D pair twice, once per orientation. A USB 2.0 device shorts A6 to B6 and A7 to B7 so the link works either way up. That is correct, not a shortcut.

Route them to U1 GPIO20 (D+) and GPIO19 (D-) as a differential pair - matched length, ~90 ohm differential, no stubs, and keep them away from the switcher and the motor traces. Espressif reference designs connect these straight to the module with no series resistors; 0 ohm placeholders are cheap insurance if you want tuning options later.

### VBUS on a board that also has 24 V

Two supplies can reach the 5 V rail, so decide which wins:

| Approach | Behaviour |
|---|---|
| **VBUS through a Schottky to the 5 V rail** (recommended) | USB alone powers the logic for flashing and configuration; the buck powers it when 24 V is present. The diode stops the buck back-feeding the host |
| Leave VBUS unconnected | Simplest and fully safe, but the board cannot be flashed or configured without the 24 V supply on |

The Schottky option has a real safety benefit worth naming: with USB only, the logic runs and the web UI is reachable while **the motors cannot move**, because the drivers have no VM. That is a good state for firmware work and configuration.

Set the buck feedback for about 5.1 V rather than exactly 5.0 V, so when both sources are present the buck reliably wins and the VBUS diode stays reverse biased.

### The VBUS Schottky

**SS34** (40 V, 3 A, SMA) or a Nexperia PMEG equivalent.

| Spec | Target | Why |
|---|---|---|
| Vf | as low as practical, ~0.35 V at 250 mA | It comes straight off the LDO's headroom on USB-only power. Read it off the Vf-vs-If curve at 250 mA, not the summary table, which quotes full rating |
| If | >=1 A | Draw is at most 500 mA - the 5.1k CC resistors advertise USB default current - but a bigger die also means lower Vf at 250 mA |
| **VR** | **>=40 V** | Fault case, not normal operation |
| Package | SMA or SMB | Lower thermal resistance, bigger die, lower Vf |

The reverse-voltage target is the non-obvious one. In normal operation this diode sees about 5 V reverse, so a 20 V part looks generous. But if the buck ever fails short, 24 V lands on the 5 V rail, and **this diode is the only thing between that fault and the host USB port**. A 20 V part breaks down and passes it through. A 40 V part costs the same and turns "kills the laptop" into "blows the fuse".

Pair it with the **AP7361C-33E-13** LDO rather than a 1117-family part. The Schottky drop plus a 1 V dropout leaves only ~100 mV of margin from a 4.75 V VBUS; the AP7361C's 140 mV dropout leaves ~960 mV. See HARDWARE.md.

### ESD

Fit a **USBLC6-2SC6** (or equivalent) on D+, D- and VBUS, close to the connector. A USB port is the most exposed net on the board and the ESP32-S3's USB pins are not otherwise protected.

### No auto-reset circuit needed

The ESP32-S3 enumerates natively over USB Serial/JTAG, so the DTR/RTS transistor pair that a CP2102-based design needs is not required. Keep the **BOOT (GPIO0) and RESET (EN) buttons** anyway - they are the recovery path if firmware ever wedges the USB stack.

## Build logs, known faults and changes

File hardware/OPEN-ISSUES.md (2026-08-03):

# Schematic open issues

Worklist against `ufluidics.kicad_sch` as of **2026-08-02**, from `kicad-cli sch erc` plus a netlist review.
State at that point: **0 ERC violations**, and several problems ERC cannot see.

Reproduce both checks with:

```
cd hardware
kicad-cli sch erc --output /tmp/erc.rpt --severity-all ufluidics.kicad_sch
kicad-cli sch export netlist --format kicadsexpr --output /tmp/net.net ufluidics.kicad_sch
```

ERC catches dangling and unconnected pins.
It does not catch a net that is wired to the wrong pin, so the netlist review is the one that found the VSW and USB faults.
A clean ERC run therefore closes out the first category and says nothing about the second - everything below survived a clean run.

**No E-stop is a deliberate choice on this board.**
`DRIVER_EN` runs straight from U1 pad 9 (GPIO16) to all five driver EN pins, GPIO14 carries a no-connect flag, and there is no J-ESTOP connector.
Do not re-file this as a defect.
The consequence is that stopping depends on firmware, which raises the value of two things that are not the E-stop: R12 holding the drivers disabled from reset, and `DRV_STATUS` readback over the driver UART. Both are present and working.

---

## Blocking

### No open blocking items

The driver socket wiring was the last one, and it is resolved: **the pin locations are correct as routed.** Pin 4 carries the single-wire PDN_UART, pin 5 is the alternate PDN pad and correctly No-Connect, pin 6 is CLK tied to GND, and the power row runs GND on pin 1 with VIO on pin 2. `CONNECTIONS.md` now carries the full as-wired table under "As-wired socket pinout - verified, do not re-derive"; read that instead of re-deriving it from the generic StepStick order, which is what produced two wrong findings during review.

Register readback therefore works. `test_connection()`, `DRV_STATUS`, CRC checking and StallGuard are all available over the existing bus, with no added parts. Do **not** fit an external 1k between pins 4 and 5 - the module already has one, and a second in series makes 2k.

---

## Important

### 1. Most parts have no footprint

**60 of 84 components.** Blocks layout, not review. Footprints that are set and worth keeping: D1 `D_SMA`, D2 `D_SMA`, D7 `D_MiniMELF`, D8 `PCM_JLCPCB:D_SMB`, Q1 `TO-252-2`, U3 `SOT-223-3_TabPin2`, U5 `SOIC-8`, F1 5x20 mm holder.

### 2. C9 is an electrolytic on an unpolarized symbol

`C9`, 470 uF on `+24V`, still uses `Device:C`. That symbol draws no polarity marking and lets a footprint be chosen with no anode. `Cout1`/`Cout2` had the same problem and are fixed; C9 was left alone because it was outside the reported scope.

470 uF on a 24 V rail is an aluminium electrolytic, and fitted backwards it vents. Move it to `Device:C_Polarized` with a `CP_*` footprint, and confirm pin 1 lands on `+24V` rather than GND after the swap - that is the step that bit `Cout1`/`Cout2`.

`C20` (1 uF at the LDO input) is fine as `Device:C`. At that value it is a ceramic, and unpolarized is correct.

### 3. Annotation errors on export

`kicad-cli` still warns on every export: `schematic has annotation errors`. The non-numeric refdes are `J_ENDSTOP_IN1`, `J_ENDSTOP_IN2`, `J_ENDSTOP_OUT1`-`OUT3`, `J_LED_RUN1`, `J_LED_FAULT1`, `J_LED_PWR1`, `J_RUN_SWITCH` and `J_DEBUG_UART`. KiCad treats each as unannotated.

Renaming them to plain numbered refdes is the fix; the descriptive names belong in the symbol's Description or a sheet note, not the reference field.

---

## Verify, do not assume

Things the netlist cannot tell apart, worth checking against the parts you actually order.

- **L1 is 47 uH; the 5 V nomograph at 24 V in gives 68 uH.** 47 uH is defensible, but confirm Isat clears the 2.2 A max current limit rather than the load current.
- **D1 (SS34) ORs USB VBUS onto `+5V`** with the buck output, cathode on `+5V`, anode on the VBUS net. Nothing limits how much the host supplies, and nothing prevents both sources being live at once. Confirm the buck tolerates back-feed at 5 V minus a Schottky drop, and that a USB host alone cannot brown out the +3V3 rail under motor load.
- **Panel LED headers share a resistor with the on-board LED.** `J_LED_RUN1` sits in parallel with D3 across R4, and likewise for FAULT and PWR. Two LEDs on one resistor split current by forward voltage, so the lower-Vf part takes most of it and the other looks dim. Give the panel header its own resistor, or accept that only one of the pair is the real indicator.
- **Endstop connectors are 2-pin here, 3-pin in the docs.** 2-pin is correct with firmware pullups and NC switches - fix `CONNECTIONS.md`, not the schematic.
- **Motor coil polarity.** Pairing is correct on all five, so no damage risk. One coil's polarity is inverted relative to the documented J-Mx order, which shows up as a reversed direction, not a fault.

---

## Already fixed

Recorded so the next review does not re-flag them.

| Was | Now |
|---|---|
| `Cout1`/`Cout2` dielectric unspecified | Both are now `Device:C_Polarized`, footprint `Capacitor_Tantalum_SMD:CP_EIA-7343-31_Kemet-D`, with `Dielectric`, `Voltage`, `ESR` and `MPN` fields carrying the constraint into the BOM. Pin 1 (+) sits on `+5V`, pin 2 on GND - verified in the netlist after the symbol swap. **`MPN` is still `TBD`** - fill it from a distributor page once you have confirmed the part's ESR |
| No input protection at all | F1, Q1, R11 100k, D7 (BZV55C15, cathode on `+24V`) and C9 470 uF all present and correctly wired |
| Input TVS on the gate node, wrong part, ambiguous symbol | D6 retired. **D8** replaces it: `TVS-Uni,SMBJ26A` from the JLCPCB library, footprint `PCM_JLCPCB:D_SMB`, pin 1 on `+24V` and pin 2 on `GND`. Value, symbol and description now agree - 26 V standoff, 42.1 V clamp, under the LM2675's 45 V absmax. Worth one look in the footprint editor that pad 1 is the banded end, since the symbol pins are unnamed |
| `DRIVER_EN` floating from reset | R12, 10k from `DRIVER_EN` to `+3V3`. Drivers are disabled until firmware pulls GPIO16 low |
| No local input cap at the LDO | C20, 1 uF on `+5V` at U3 VI |
| No J-DBG header | `J_DEBUG_UART`, 3-pin: `/DEBUG_RX` (U1 pad 36), `/DEBUG_TX` (pad 37), GND |
| `J_ENDSTOP_OUT4` was really the RUN switch | Renamed `J_RUN_SWITCH`, on `/RUN_SWITCH` to GPIO13 |
| `single_global_label` disabled | Back on. Only `footprint_filter`, `four_way_junction` and `simulation_model_issue` remain ignored, all harmless. `erc_exclusions` is empty |
| 24 V bulk at ~14 uF | C9 470 uF at the input |
| No per-driver VMOT decoupling | C10-C19, ten parts on `+24V`, one pair per driver socket |
| Three `power_pin_not_driven` errors | PWR_FLAGs added in `power.kicad_sch`. `+3V3` is additionally driven by U3 pin 3 (`power_out`) |
| I2C pullups unset | R9 and R10 both 4.7k |
| J19 pin order reversed against the docs | Pin 3 = SDA, pin 4 = SCL, matching `CONNECTIONS.md` |
| Stray `POT_B` label | Deleted |
| Stray `ESTOP_SENSE` label | Deleted; GPIO14 (pad 22) now carries a no-connect flag |
| Missing no-connect flags | U1 pads 15, 22, 36, 37; U5 pads 2, 3 and 5; J20 pad 9; J21 SBU1/SBU2. Floating ON/OFF on U5 is correct - the pin sources its own bias - and now reads as intent |
| Off-grid endpoints around J17 | Cleared |
| U5 pad 8 (VSW) unconnected, FB wired to the switch node | VSW joins C1/D2/L1; FB on `+5V` |
| USB D+/D- crossed at the MCU | `USB_DP` and `USB_DN` both straight through |
| No capacitance at all on +3V3 | C6 22 uF, C7 100 nF, C8 1 uF on the LDO output |
| EN cap 100 nF | C2 = 1 uF |
| No pot wiper filtering | C4, C5 at 100 nF |
| `USB_C_Plug` symbol, single 5.1k | `USB_C_Receptacle_USB2.0_16P`, R1 and R8 as separate Rd on CC1 and CC2 |

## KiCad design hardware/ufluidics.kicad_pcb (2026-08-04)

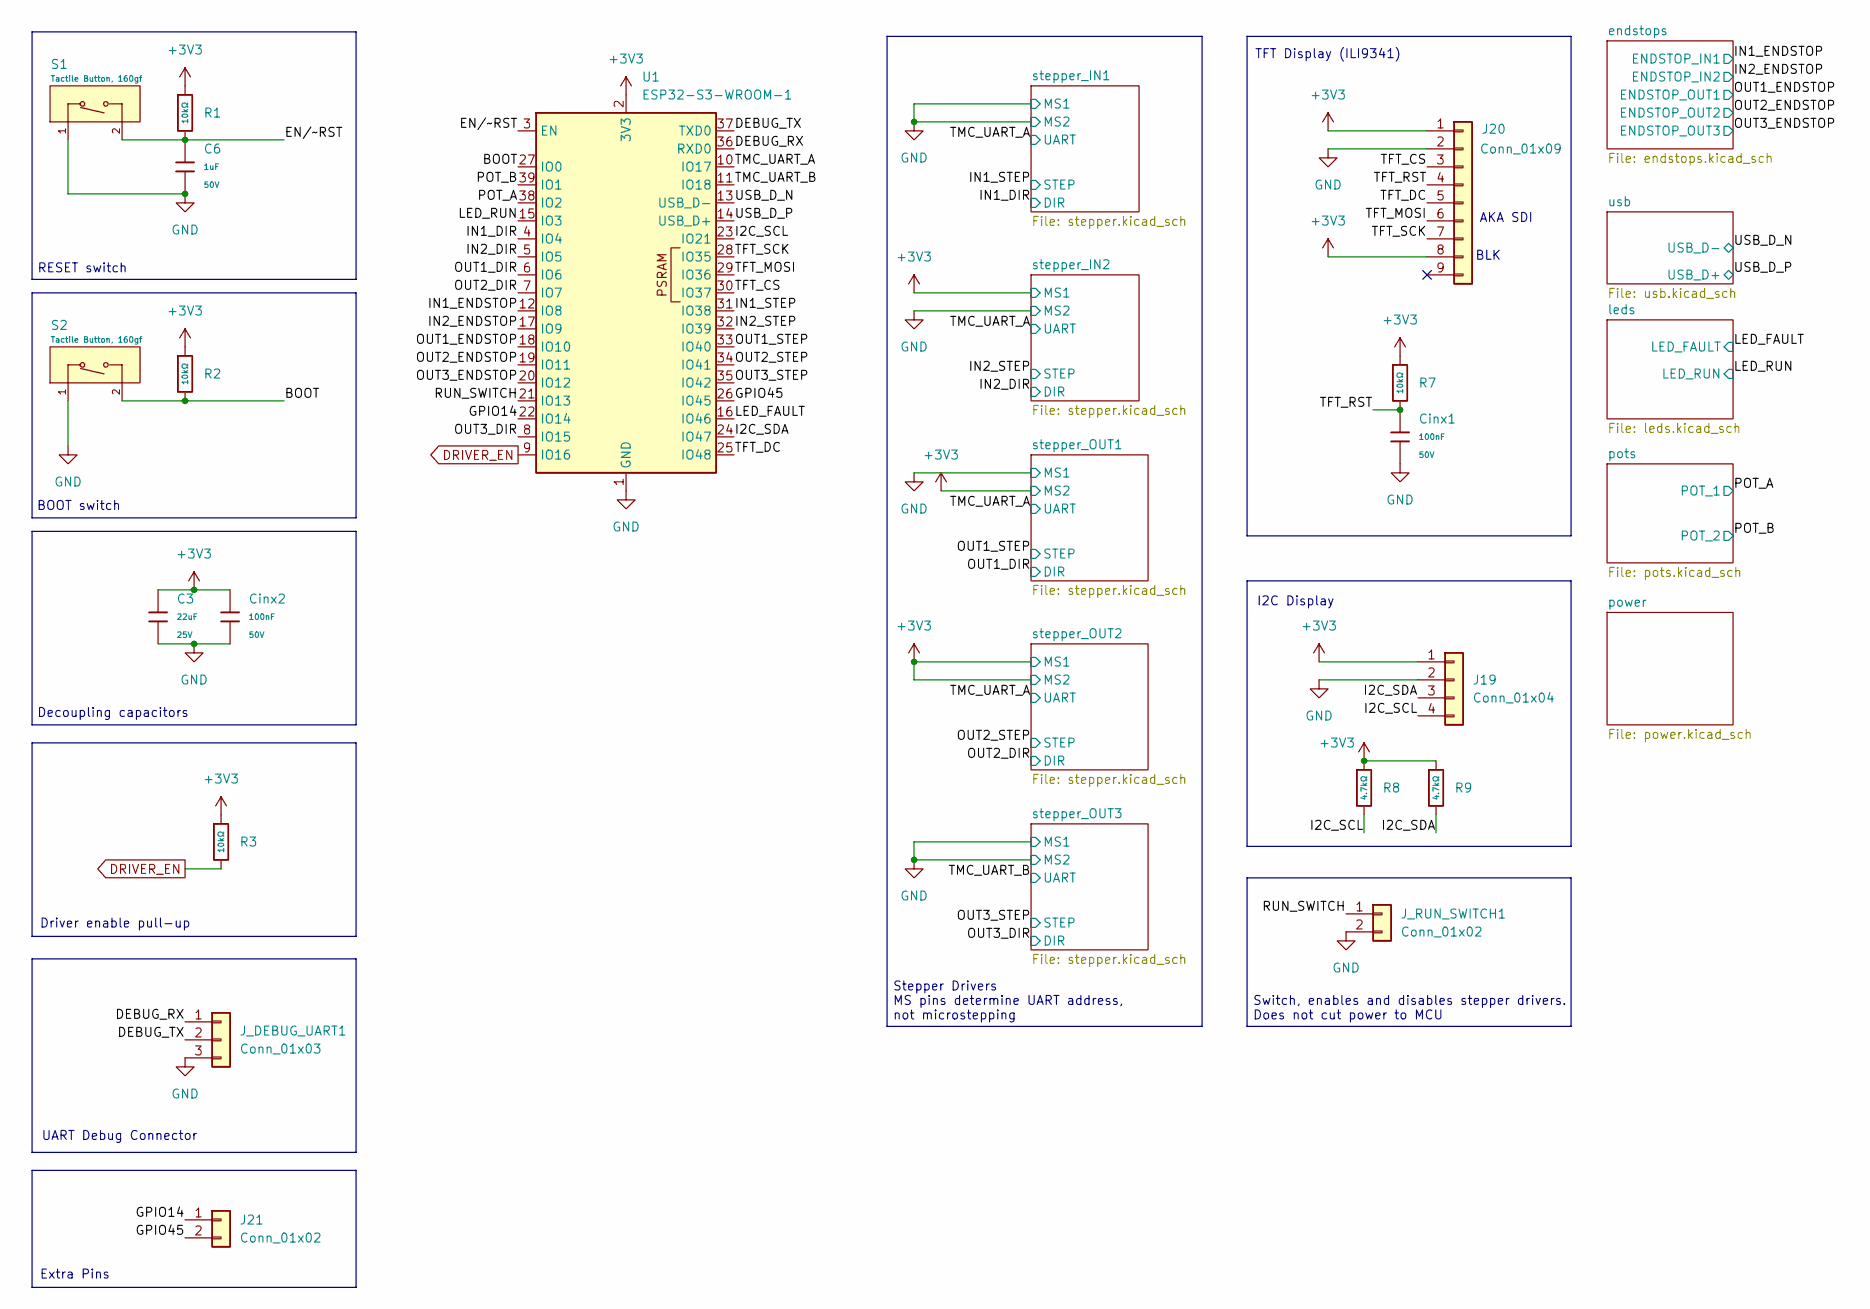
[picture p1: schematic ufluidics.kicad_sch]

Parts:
C3: 22uF; C_0805; Voltage Rated 25V; Tolerance ±20%; Part CL21A226MAQNNNE; LCSC C45783
C6: 1uF; C_0805; Voltage Rated 50V; Tolerance ±10%; Part CL21B105KBFNNNE; LCSC C28323
Cinx1, Cinx2: 100nF; C_0402; Voltage Rated 50V; Tolerance ±10%; Part CL05B104KB54PNC; LCSC C307331
J19: Conn_01x04; JST_XH_B4B-XH-A_1x04_P2.50mm_Vertical
J20: Conn_01x09; JST_XH_B9B-XH-A_1x09_P2.50mm_Vertical
J21: Conn_01x02; PinHeader_1x02_P2.54mm_Vertical
J_DEBUG_UART1: Conn_01x03; JST_XH_B3B-XH-A_1x03_P2.50mm_Vertical
J_RUN_SWITCH1: Conn_01x02; JST_XH_B2B-XH-A_1x02_P2.50mm_Vertical
R1, R2, R3, R7: 10kΩ; R_0603; Overload Voltage (Max) 75V; Tolerance ±1%; Part 0603WAF1002T5E; LCSC C25804
R8, R9: 4.7kΩ; R_0603; Overload Voltage (Max) 75V; Tolerance ±1%; Part 0603WAF4701T5E; LCSC C23162
S1, S2: Tactile Button, 160gf; SW_TS-1088-AR02016; Voltage Rating (Dc) 12V; Part TS-1088-AR02016; LCSC C720477
U1: ESP32-S3-WROOM-1

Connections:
+3V3: C3.1, Cinx2.1, J19.1, J20.1, J20.8, R1.1, R2.1, R3.1, R7.1, R8.1, R9.1, U1.2 (3V3); also elsewhere on the board
/BOOT: R2.2, S2.2 (B), U1.27 (IO0)
/DEBUG_RX: J_DEBUG_UART1.1, U1.36 (RXD0)
/DEBUG_TX: J_DEBUG_UART1.2, U1.37 (TXD0)
/EN/~RST: C6.1, R1.2, S1.2 (B), U1.3 (EN)
/GPIO14: J21.1, U1.22 (IO14)
/GPIO45: J21.2, U1.26 (IO45)
/I2C_SCL: J19.4, R8.2, U1.23 (IO21)
/I2C_SDA: J19.3, R9.2, U1.24 (IO47)
/IN1_DIR: U1.4 (IO4); also elsewhere on the board
/IN1_ENDSTOP: U1.12 (IO8); also elsewhere on the board
/IN1_STEP: U1.31 (IO38); also elsewhere on the board
/IN2_DIR: U1.5 (IO5); also elsewhere on the board
/IN2_ENDSTOP: U1.17 (IO9); also elsewhere on the board
/IN2_STEP: U1.32 (IO39); also elsewhere on the board
/LED_FAULT: U1.16 (IO46); also elsewhere on the board
/LED_RUN: U1.15 (IO3); also elsewhere on the board
/OUT1_DIR: U1.6 (IO6); also elsewhere on the board
/OUT1_ENDSTOP: U1.18 (IO10); also elsewhere on the board
/OUT1_STEP: U1.33 (IO40); also elsewhere on the board
/OUT2_DIR: U1.7 (IO7); also elsewhere on the board
/OUT2_ENDSTOP: U1.19 (IO11); also elsewhere on the board
/OUT2_STEP: U1.34 (IO41); also elsewhere on the board
/OUT3_DIR: U1.8 (IO15); also elsewhere on the board
/OUT3_ENDSTOP: U1.20 (IO12); also elsewhere on the board
/OUT3_STEP: U1.35 (IO42); also elsewhere on the board
/POT_A: U1.38 (IO2); also elsewhere on the board
/POT_B: U1.39 (IO1); also elsewhere on the board
/RUN_SWITCH: J_RUN_SWITCH1.1, U1.21 (IO13)
/TFT_CS: J20.3, U1.30 (IO37)
/TFT_DC: J20.5, U1.25 (IO48)
/TFT_MOSI: J20.6, U1.29 (IO36)
/TFT_RST: Cinx1.1, J20.4, R7.2
/TFT_SCK: J20.7, U1.28 (IO35)
/TMC_UART_A: U1.10 (IO17); also elsewhere on the board
/TMC_UART_B: U1.11 (IO18); also elsewhere on the board
/USB_D_N: U1.13 (USB_D-); also elsewhere on the board
/USB_D_P: U1.14 (USB_D+); also elsewhere on the board
DRIVER_EN: R3.2, U1.9 (IO16); also elsewhere on the board
GND: C3.2, C6.2, Cinx1.2, Cinx2.2, J19.2, J20.2, J_DEBUG_UART1.3, J_RUN_SWITCH1.2, S1.1 (A), S2.1 (A), U1.1 (GND), U1.40 (GND), U1.41 (GND); also elsewhere on the board

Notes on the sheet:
AKA SDI
BOOT switch
UART Debug Connector
I2C Display
Driver enable pull-up
Stepper Drivers MS pins determine UART address, not microstepping
BLK
RESET switch
Extra Pins
Switch, enables and disables stepper drivers. Does not cut power to MCU
TFT Display (ILI9341)
Decoupling capacitors

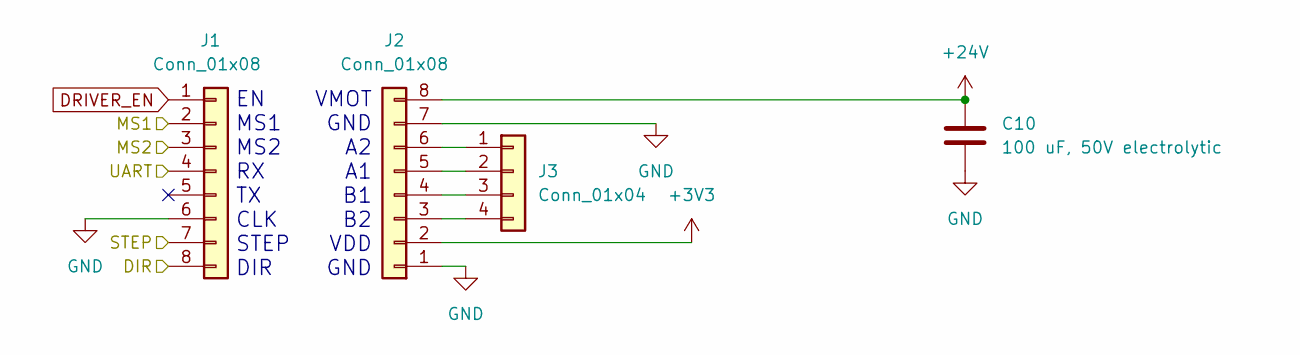
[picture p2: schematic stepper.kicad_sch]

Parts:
C10: 100 uF, 50V electrolytic; C_Radial_D8.0mm_H11.5mm_P3.50mm; MFR Part# KM107M050F12RR0VH2FP0; JLC Part# C2749
J1, J2: Conn_01x08; PinSocket_1x08_P2.54mm_Vertical
J3: Conn_01x04; PinHeader_1x04_P2.54mm_Vertical

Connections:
+3V3: J2.2; also elsewhere on the board
+24V: C10.1, J2.8; also elsewhere on the board
/IN1_DIR: J1.8; also elsewhere on the board
/IN1_STEP: J1.7; also elsewhere on the board
/TMC_UART_A: J1.4; also elsewhere on the board
DRIVER_EN: J1.1; also elsewhere on the board
GND: C10.2, J1.2, J1.3, J1.6, J2.1, J2.7; also elsewhere on the board
unnamed: J2.3, J3.4
unnamed: J2.4, J3.3
unnamed: J2.5, J3.2
unnamed: J2.6, J3.1

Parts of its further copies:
C11, C12, C13, C14: 100 uF, 50V electrolytic; C_Radial_D8.0mm_H11.5mm_P3.50mm; MFR Part# KM107M050F12RR0VH2FP0; JLC Part# C2749
J4, J5, J7, J8, J10, J11, J13, J14: Conn_01x08; PinSocket_1x08_P2.54mm_Vertical
J6, J9, J12, J15: Conn_01x04; PinHeader_1x04_P2.54mm_Vertical

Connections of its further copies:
+3V3: J4.2, J5.2, J7.3, J8.2, J10.2, J10.3, J11.2, J14.2; also elsewhere on the board
+24V: C11.1, C12.1, C13.1, C14.1, J5.8, J8.8, J11.8, J14.8; also elsewhere on the board
/IN2_DIR: J4.8; also elsewhere on the board
/IN2_STEP: J4.7; also elsewhere on the board
/OUT1_DIR: J7.8; also elsewhere on the board
/OUT1_STEP: J7.7; also elsewhere on the board
/OUT2_DIR: J10.8; also elsewhere on the board
/OUT2_STEP: J10.7; also elsewhere on the board
/OUT3_DIR: J13.8; also elsewhere on the board
/OUT3_STEP: J13.7; also elsewhere on the board
/TMC_UART_A: J4.4, J7.4, J10.4; also elsewhere on the board
/TMC_UART_B: J13.4; also elsewhere on the board
DRIVER_EN: J4.1, J7.1, J10.1, J13.1; also elsewhere on the board
GND: C11.2, C12.2, C13.2, C14.2, J4.3, J4.6, J5.1, J5.7, J7.2, J7.6, J8.1, J8.7, J10.6, J11.1, J11.7, J13.2, J13.3, J13.6, J14.1, J14.7; also elsewhere on the board
unnamed: J5.3, J6.4
unnamed: J5.4, J6.3
unnamed: J5.5, J6.2
unnamed: J5.6, J6.1
unnamed: J8.3, J9.4
unnamed: J8.4, J9.3
unnamed: J8.5, J9.2
unnamed: J8.6, J9.1
unnamed: J11.3, J12.4
unnamed: J11.4, J12.3
unnamed: J11.5, J12.2
unnamed: J11.6, J12.1
unnamed: J14.3, J15.4
unnamed: J14.4, J15.3
unnamed: J14.5, J15.2
unnamed: J14.6, J15.1

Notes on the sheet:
VMOT GND A2 A1 B1 B2 VDD GND
EN MS1 MS2 RX TX CLK STEP DIR

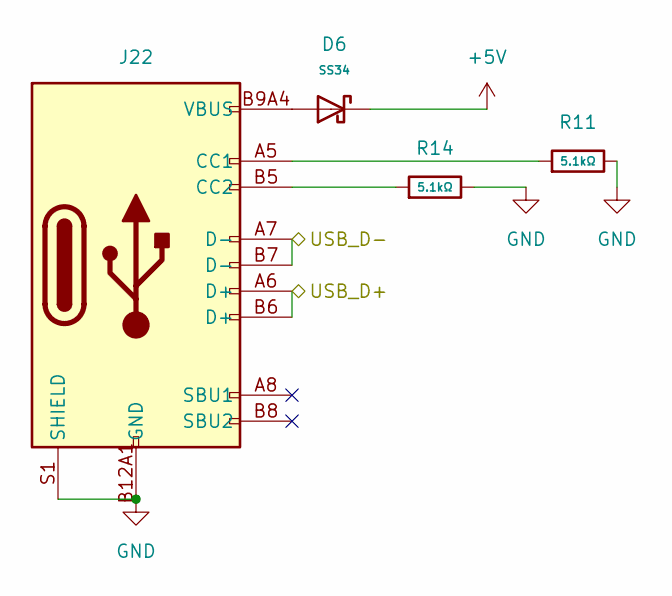
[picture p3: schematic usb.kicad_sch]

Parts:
D6: SS34; D_SMA; Forward Voltage (Vf@If) 550mV@3A; Reverse Voltage (Vr) 40V; Part SS34; LCSC C8678
J22: Connector, USB-TYPE-C-16P; TYPE-C-SMD_HX-TYPE-C-16PIN; LCSC C2927039
R11, R14: 5.1kΩ; R_0603; Overload Voltage (Max) 75V; Tolerance ±1%; Part 0603WAF5101T5E; LCSC C23186

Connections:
+5V: D6.1; also elsewhere on the board
/USB_D_N: J22.A7 (D-), J22.B7 (D-); also elsewhere on the board
/USB_D_P: J22.A6 (D+), J22.B6 (D+); also elsewhere on the board
GND: J22.A12B1 (GND), J22.B12A1 (GND), J22.S1 (SHIELD), R11.2, R14.2; also elsewhere on the board
unnamed: D6.2, J22.A9B4 (VBUS), J22.B9A4 (VBUS)
unnamed: J22.A5 (CC1), R11.1
unnamed: J22.B5 (CC2), R14.1

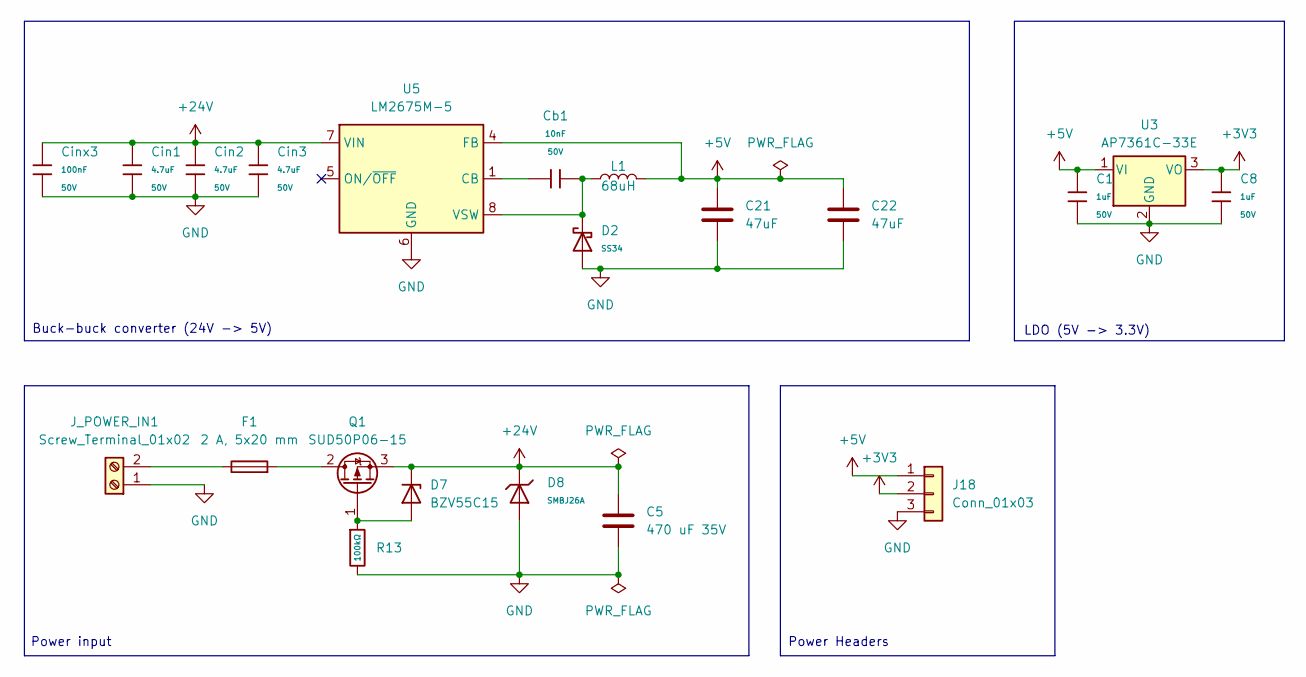
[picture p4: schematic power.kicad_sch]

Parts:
C1, C8: 1uF; C_0805; Voltage Rated 50V; Tolerance ±10%; Part CL21B105KBFNNNE; LCSC C28323
C5: 470 uF 35V; C_Radial_D10.0mm_H16.0mm_P5.00mm; MFR Part# ERS1VM471G16OT; JLC Part# C106703
C21, C22: 47uF; C_1210_3225Metric; MFR Part# GRM32ER61C476KE15L; JLC Part# C77101
Cb1: 10nF; C_0805; Voltage Rated 50V; Tolerance ±10%; Part CL21B103KBANNNC; LCSC C1710
Cin1, Cin2, Cin3: 4.7uF; C_1206; Voltage Rated 50V; Tolerance ±10%; Part 1206B475K500NT; LCSC C29823
Cinx3: 100nF; C_0402; Voltage Rated 50V; Tolerance ±10%; Part CL05B104KB54PNC; LCSC C307331
D2: SS34; D_SMA; Forward Voltage (Vf@If) 550mV@3A; Reverse Voltage (Vr) 40V; Part SS34; LCSC C8678
D7: BZV55C15; D_MiniMELF
D8: SMBJ26A; D_SMB; Part SMBJ26A; LCSC C19077580
F1: 2 A, 5x20 mm; Fuseholder_Cylinder-5x20mm_Stelvio-Kontek_PTF78_Horizontal_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; JLC Part# C3130
J18: Conn_01x03; PinHeader_1x03_P2.54mm_Vertical
J_POWER_IN1: Screw_Terminal_01x02; TerminalBlock_4Ucon_1x02_P3.50mm_Horizontal
L1: 68uH; L_SXN_SMDRI127; MFR Part# SMDRI127-680MT; JLC Part# C9907
Q1: SUD50P06-15; TO-252-2
R13: 100kΩ; R_0603; Overload Voltage (Max) 75V; Tolerance ±1%; Part 0603WAF1003T5E; LCSC C25803
U3: AP7361C-33E; SOT-223-3_TabPin2
U5: LM2675M-5; SOIC-8_3.9x4.9mm_P1.27mm

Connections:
+3V3: C8.1, J18.2, U3.3 (VO); also elsewhere on the board
+5V: C1.1, C21.1, C22.1, J18.1, L1.2, U3.1 (VI), U5.4 (FB); also elsewhere on the board
+24V: C5.1, Cin1.1, Cin2.1, Cin3.1, Cinx3.1, D7.1 (K), D8.1, Q1.3 (S), U5.7 (VIN); also elsewhere on the board
GND: C1.2, C5.2, C8.2, C21.2, C22.2, Cin1.2, Cin2.2, Cin3.2, Cinx3.2, D2.2, D8.2, J18.3, J_POWER_IN1.1, R13.2, U3.2 (GND), U5.6 (GND); also elsewhere on the board
unnamed: D7.2 (A), Q1.1 (G), R13.1
unnamed: F1.1, J_POWER_IN1.2
unnamed: F1.2, Q1.2 (D)
unnamed: Cb1.1, U5.1 (CB)
unnamed: Cb1.2, D2.1, L1.1, U5.8 (VSW)

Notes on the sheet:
Power input
Power Headers
LDO (5V -> 3.3V)
Buck-buck converter (24V -> 5V)

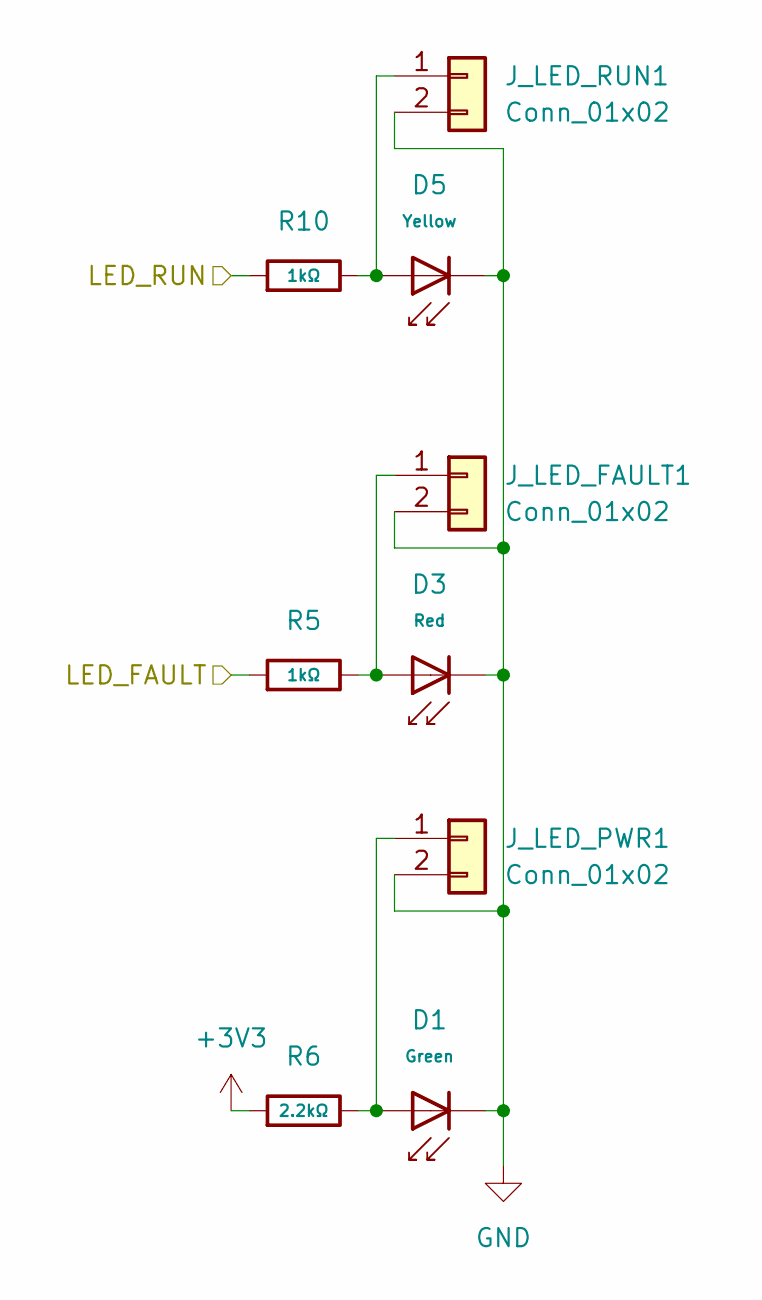
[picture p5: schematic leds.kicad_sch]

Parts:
D1: Green; D_0805; Part KT-0805G; LCSC C2297
D3: Red; D_0603; Part KT-0603R; LCSC C2286
D5: Yellow; D_0603; Forward Voltage (VF) 1.6V~2.6V; Part NCD0603Y2; LCSC C89811
J_LED_FAULT1: Conn_01x02; JST_PH_B2B-PH-K_1x02_P2.00mm_Vertical
J_LED_PWR1: Conn_01x02; JST_PH_B2B-PH-K_1x02_P2.00mm_Vertical
J_LED_RUN1: Conn_01x02; JST_PH_B2B-PH-K_1x02_P2.00mm_Vertical
R5, R10: 1kΩ; R_0603; Overload Voltage (Max) 75V; Tolerance ±1%; Part 0603WAF1001T5E; LCSC C21190
R6: 2.2kΩ; R_0603; Overload Voltage (Max) 75V; Tolerance ±1%; Part 0603WAF2201T5E; LCSC C4190

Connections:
+3V3: R6.1; also elsewhere on the board
/LED_FAULT: R5.1; also elsewhere on the board
/LED_RUN: R10.1; also elsewhere on the board
GND: D1.1, D3.1, D5.1, J_LED_FAULT1.2, J_LED_PWR1.2, J_LED_RUN1.2; also elsewhere on the board
unnamed: D3.2, J_LED_FAULT1.1, R5.2
unnamed: D1.2, J_LED_PWR1.1, R6.2
unnamed: D5.2, J_LED_RUN1.1, R10.2

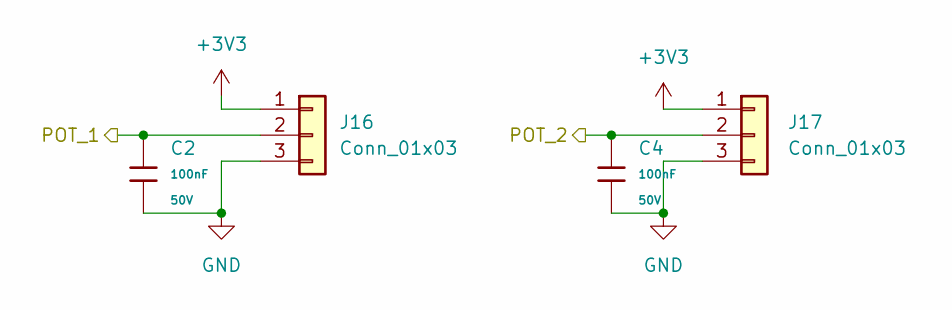
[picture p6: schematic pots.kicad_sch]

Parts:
C2, C4: 100nF; C_0402; Voltage Rated 50V; Tolerance ±10%; Part CL05B104KB54PNC; LCSC C307331
J16, J17: Conn_01x03; JST_XH_B3B-XH-A_1x03_P2.50mm_Vertical

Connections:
+3V3: J16.1, J17.1; also elsewhere on the board
/POT_A: C2.1, J16.2; also elsewhere on the board
/POT_B: C4.1, J17.2; also elsewhere on the board
GND: C2.2, C4.2, J16.3, J17.3; also elsewhere on the board

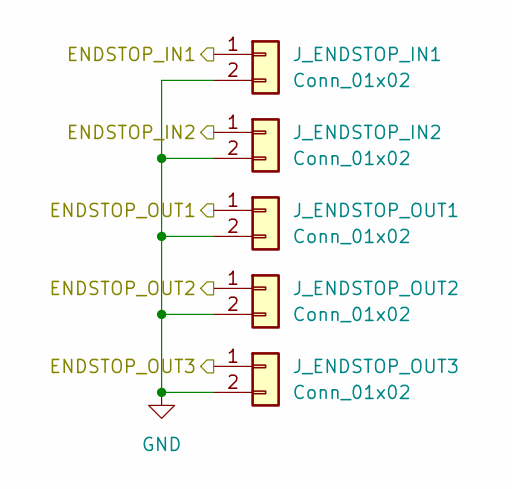
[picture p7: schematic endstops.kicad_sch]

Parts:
J_ENDSTOP_IN1, J_ENDSTOP_IN2: Conn_01x02; JST_XH_B2B-XH-A_1x02_P2.50mm_Vertical
J_ENDSTOP_OUT1, J_ENDSTOP_OUT2, J_ENDSTOP_OUT3: Conn_01x02; JST_XH_B2B-XH-A_1x02_P2.50mm_Vertical

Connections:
/IN1_ENDSTOP: J_ENDSTOP_IN1.1; also elsewhere on the board
/IN2_ENDSTOP: J_ENDSTOP_IN2.1; also elsewhere on the board
/OUT1_ENDSTOP: J_ENDSTOP_OUT1.1; also elsewhere on the board
/OUT2_ENDSTOP: J_ENDSTOP_OUT2.1; also elsewhere on the board
/OUT3_ENDSTOP: J_ENDSTOP_OUT3.1; also elsewhere on the board
GND: J_ENDSTOP_IN1.2, J_ENDSTOP_IN2.2, J_ENDSTOP_OUT1.2, J_ENDSTOP_OUT2.2, J_ENDSTOP_OUT3.2; also elsewhere on the board

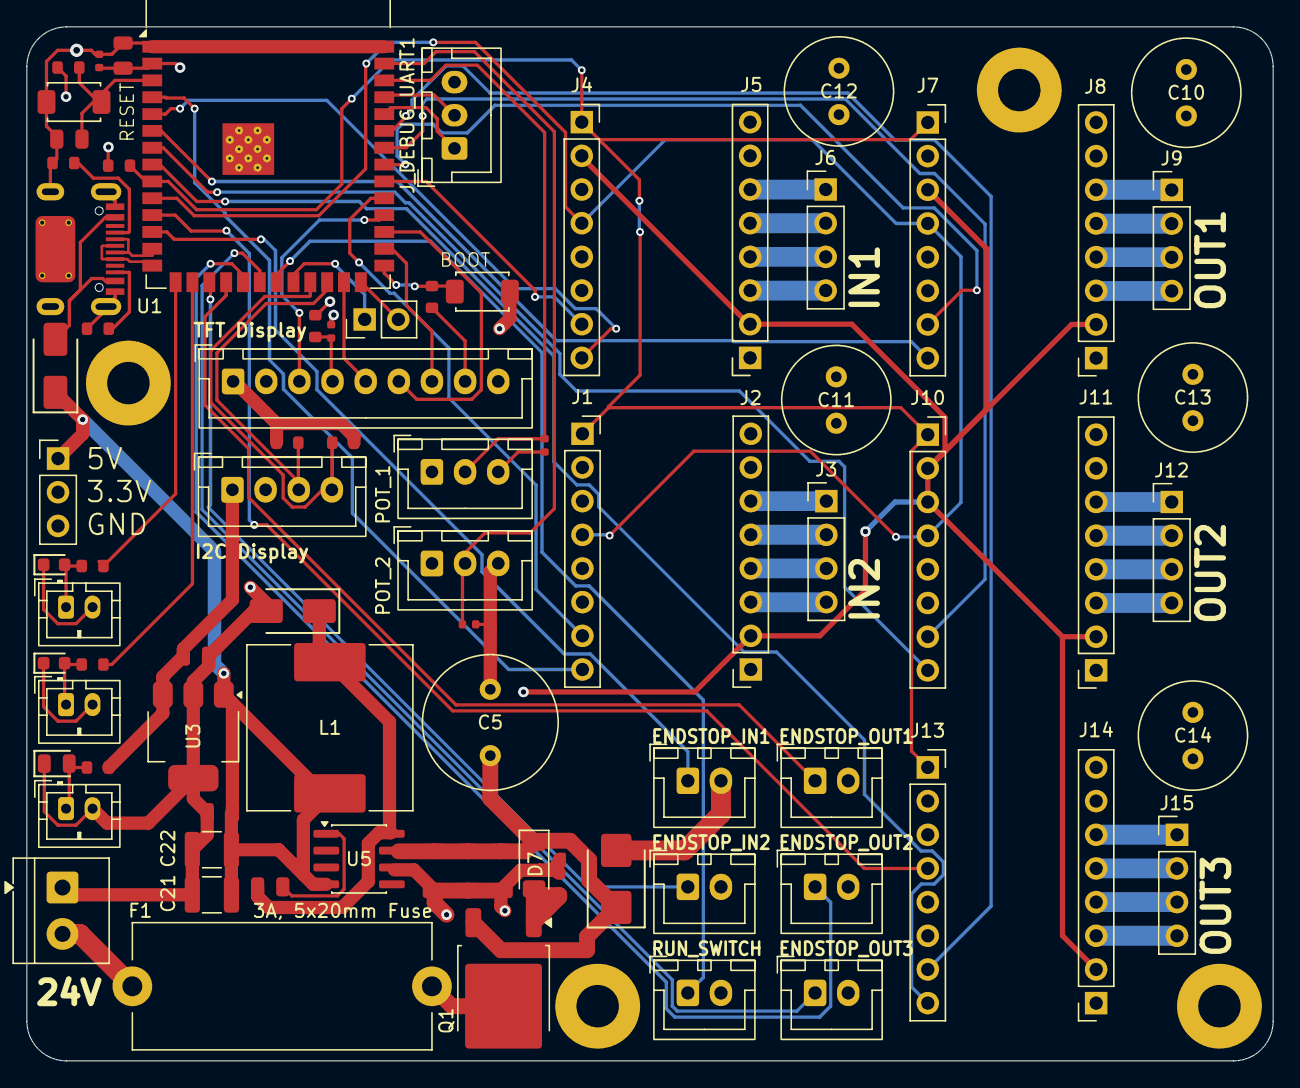
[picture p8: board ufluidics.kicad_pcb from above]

Board: 4 copper layers, 94.0 x 78.0 mm, 81 parts (0 on the bottom side), 73 nets.

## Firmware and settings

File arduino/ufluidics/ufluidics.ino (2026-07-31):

// ufluidics.ino - zero-sum five-pump syringe controller for an Elegoo Mega 2560 R3.
//
// Two input pumps push a fixed total flow into the microfluidic device at a
// fixed ratio to each other. Three output pumps withdraw exactly that same
// total, split three ways. Two potentiometers set the output split live; a
// maintained switch arms the system.
//
// Because every pump is derived from one total, mass balance holds by
// construction rather than by tuning: the three output fractions sum to 1.0
// and both inputs and outputs scale from the same number.
//
// Requires the AccelStepper library (Mike McCauley).
// Arduino IDE: Tools > Manage Libraries > search "AccelStepper".
//
// All tunables live in config.h.

#include <AccelStepper.h>

#include "config.h"

// ---------------------------------------------------------------------------
// Steppers
// ---------------------------------------------------------------------------
//
// Constant-speed mode only: runSpeed() is polled every loop iteration and no
// acceleration ramp is used. Steady volumetric flow is the entire point, and a
// ramp would corrupt the mass balance every time a pot moved.

static AccelStepper g_pump[N_PUMPS] = {
  AccelStepper(AccelStepper::DRIVER, STEP_PIN[0], DIR_PIN[0]),
  AccelStepper(AccelStepper::DRIVER, STEP_PIN[1], DIR_PIN[1]),
  AccelStepper(AccelStepper::DRIVER, STEP_PIN[2], DIR_PIN[2]),
  AccelStepper(AccelStepper::DRIVER, STEP_PIN[3], DIR_PIN[3]),
  AccelStepper(AccelStepper::DRIVER, STEP_PIN[4], DIR_PIN[4]),
};

// ---------------------------------------------------------------------------
// Controller state
// ---------------------------------------------------------------------------

enum State : uint8_t { ST_IDLE, ST_RUNNING, ST_FAULT };

static State g_state = ST_IDLE;

// Blocks arming until the RUN switch has been seen open at least once since
// boot. See the power-up note in loop().
static bool g_armInhibit = true;

static float g_flowUlS[N_PUMPS];       // commanded flow per pump, uL/s
static float g_fraction[N_PUMPS];      // each pump's share of total flow

static int32_t  g_potAcc[N_POTS];      // EMA accumulators, raw << POT_EMA_SHIFT
static uint16_t g_potApplied[N_POTS];  // last value that actually moved the rates

// ---------------------------------------------------------------------------
// Non-blocking serial
//
// Serial.print() blocks once the 64-byte UART buffer fills, and anything that
// blocks stops runSpeed() from being polled. AccelStepper timestamps each step
// as it happens rather than against a fixed schedule, so a stalled loop turns
// directly into lost volume that is never made up. Telemetry is therefore
// staged in a buffer and drained only as fast as the UART has room.
// ---------------------------------------------------------------------------

#define TX_BUF_SIZE 256

static char    s_tx[TX_BUF_SIZE];
static uint16_t s_txLen = 0;
static uint16_t s_txPos = 0;

static bool txIdle() { return s_txPos >= s_txLen; }

static void txBegin() { s_txLen = 0; s_txPos = 0; }

// Always keeps two bytes in reserve for the terminator. Without that, an
// over-long line silently loses its newline instead of its tail, and every
// subsequent line merges into one unreadable run - which looks exactly like
// telemetry having stopped.
static void txStr(const char *s) {
  while (*s && s_txLen < TX_BUF_SIZE - 2) s_tx[s_txLen++] = *s++;
}

static void txEol() {
  s_tx[s_txLen++] = '\r';
  s_tx[s_txLen++] = '\n';
}

static void txFloat(float v, uint8_t decimals) {
  char b[14];
  dtostrf(v, 0, decimals, b);
  txStr(b);
}

// Push only what fits in the UART buffer right now, then return.
static void txService() {
  int room = Serial.availableForWrite();
  while (s_txPos < s_txLen && room-- > 0) Serial.write(s_tx[s_txPos++]);
}

// ---------------------------------------------------------------------------
// Speed control
// ---------------------------------------------------------------------------

// Push the commanded flows into the steppers, or zero them when not running.
static void applySpeeds() {
  for (uint8_t i = 0; i < N_PUMPS; i++) {
    float sps = (g_state == ST_RUNNING)
                  ? g_flowUlS[i] * STEPS_PER_UL * DIR_SIGN[i]
                  : 0.0f;

    // See MIN_SPEED_SPS: below this AccelStepper's step-interval arithmetic
    // overflows and runs FASTER than asked, so stop the pump outright.
    if (fabsf(sps) < MIN_SPEED_SPS) sps = 0.0f;

    g_pump[i].setSpeed(sps);
  }
}

// Travel is tracked as steps from the assumed starting position. Position is
// signed because the outputs run backwards, so compare the magnitude.
static uint32_t stepsTaken(uint8_t i) {
  const long pos = g_pump[i].currentPosition();
  return (uint32_t)(pos < 0 ? -pos : pos);
}

// ---------------------------------------------------------------------------
// Flow math
// ---------------------------------------------------------------------------
//
// Total input flow is fixed, split between the inputs by IN2_TO_IN1_RATIO.
// POT_A sets OUT1's share of that total, POT_B sets OUT2's, and OUT3 absorbs
// the remainder. Each pot is capped at OUT_POT_MAX_FRAC, so OUT3 can never be
// starved below 1 - 2*OUT_POT_MAX_FRAC.
//
// Inputs and outputs are both derived from the same total, so mass balance
// holds at every pot position rather than only at the calibrated one.

// Map a pot reading to 0.0-1.0 across POT_RAW_MIN..POT_RAW_MAX. The outer
// counts of the sweep are deliberately discarded so both rails stay reachable;
// see POT_RAW_MIN in config.h for why that margin has to exist.
static float potFraction(uint8_t p) {
  const int16_t v = (int16_t)g_potApplied[p];
  if (v <= POT_RAW_MIN) return 0.0f;
  if (v >= POT_RAW_MAX) return 1.0f;
  return (float)(v - POT_RAW_MIN) / (float)(POT_RAW_MAX - POT_RAW_MIN);
}

static void recomputeFlows() {
  const float f2 = potFraction(0) * OUT_POT_MAX_FRAC;  // OUT1
  const float f3 = potFraction(1) * OUT_POT_MAX_FRAC;  // OUT2
  const float f4 = 1.0f - f2 - f3;                     // OUT3

  g_fraction[0] = IN1_SHARE;
  g_fraction[1] = IN2_SHARE;
  g_fraction[2] = f2;
  g_fraction[3] = f3;
  g_fraction[4] = f4;

  for (uint8_t i = 0; i < N_PUMPS; i++) g_flowUlS[i] = TOTAL_IN_UL_S * g_fraction[i];
}

// ---------------------------------------------------------------------------
// State transitions
// ---------------------------------------------------------------------------

static void enterIdle() {
  g_state = ST_IDLE;
  applySpeeds();
  digitalWrite(EN_PIN, HIGH);   // drivers off
  digitalWrite(LED_PIN, LOW);
  Serial.println(F("[state] IDLE"));
}

static void enterRunning() {
  g_state = ST_RUNNING;
  digitalWrite(EN_PIN, LOW);    // drivers on
  digitalWrite(LED_PIN, HIGH);
  applySpeeds();
  Serial.println(F("[state] RUNNING"));
}

static void enterFault(uint8_t pump) {
  g_state = ST_FAULT;
  applySpeeds();
  digitalWrite(EN_PIN, HIGH);
  Serial.print(F("[state] FAULT - end of travel on "));
  Serial.print(PUMP_NAME[pump]);
  Serial.println(F(". Reload syringes, then open the RUN switch to acknowledge."));
}

// ---------------------------------------------------------------------------
// Inputs
// ---------------------------------------------------------------------------

// Debounced position of the maintained RUN switch. Closed to GND on an
// internal pullup reads LOW, so closed = run.
//
// This is a latching switch, not a momentary button: its position IS the
// request, so the state machine follows the level rather than toggling on an
// edge. That also means the switch can be closed while the board is powered
// up, which g_armInhibit handles.
static bool runSwitchClosed() {
  static uint8_t  stable = HIGH;
  static uint8_t  last = HIGH;
  static uint32_t lastChange = 0;

  const uint8_t raw = digitalRead(BTN_PIN);
  const uint32_t now = millis();

  if (raw != last) {
    last = raw;
    lastChange = now;
  } else if ((now - lastChange) >= DEBOUNCE_MS) {
    stable = raw;
  }
  return (stable == LOW);
}

// Filter both pots and report whether either moved enough to matter. Raw ADC
// dither would otherwise make the output rates wobble continuously, so an EMA
// is followed by a deadband: a still pot produces a perfectly still flow.
// One pot per call, round-robin. analogRead() takes ~112 us, so reading all
// three back to back was a ~340 us hole in the loop - more than half a step
// interval at the top of the flow range, which shows up as lost volume because
// AccelStepper never makes up a late step. Staggering caps the hole at ~112 us.
//
// Each pot is then sampled at CONTROL_HZ/N_POTS, so the EMA settles over about
// a second. That is invisible for a hand-turned control.
static bool readPots() {
  static uint8_t p = 0;

  const int raw = analogRead(POT_PIN[p]);

  g_potAcc[p] += raw - (g_potAcc[p] >> POT_EMA_SHIFT);
  const uint16_t filtered = (uint16_t)(g_potAcc[p] >> POT_EMA_SHIFT);

  bool changed = false;
  if (abs((int)filtered - (int)g_potApplied[p]) > POT_DEADBAND) {
    g_potApplied[p] = filtered;
    changed = true;
  }

  if (++p >= N_POTS) p = 0;
  return changed;
}

// ---------------------------------------------------------------------------
// Safety
// ---------------------------------------------------------------------------
//
// Inputs start full and count down to empty; outputs start empty and count up
// to full. Both reach the same step count, so one integer comparison covers
// every pump and no floating point sits in the safety path.

static void checkTravel() {
  for (uint8_t i = 0; i < N_PUMPS; i++) {
    if (stepsTaken(i) >= STEPS_FULL_SYRINGE) {
      enterFault(i);
      return;
    }
  }
}

// ---------------------------------------------------------------------------
// Telemetry
// ---------------------------------------------------------------------------

static void printBanner() {
  Serial.println();
  Serial.println(F("=== ufluidics zero-sum five-pump controller ==="));
  Serial.print(F("microsteps        : 1/"));   Serial.println(MICROSTEPS);
  Serial.print(F("steps per mm      : "));     Serial.println(STEPS_PER_MM, 2);
  Serial.print(F("uL per mm         : "));     Serial.println(UL_PER_MM, 3);
  Serial.print(F("steps per uL      : "));     Serial.println(STEPS_PER_UL, 4);
  Serial.print(F("full stroke steps : "));     Serial.println(STEPS_FULL_SYRINGE);
  Serial.print(F("uL per step       : "));     Serial.println(1.0f / STEPS_PER_UL, 4);
  Serial.print(F("IN1 flow (fixed)  : "));     Serial.print(IN1_FLOW_UL_MIN, 1);
  Serial.print(F(" uL/min   at "));            Serial.print(MIN_IN1_SPS, 2);
  Serial.println(F(" steps/s"));
  Serial.print(F("IN2 flow (fixed)  : "));     Serial.print(IN2_FLOW_UL_MIN, 1);
  Serial.print(F(" uL/min   at "));            Serial.print(UL_MIN_TO_SPS(IN2_FLOW_UL_MIN), 2);
  Serial.println(F(" steps/s"));
  Serial.print(F("input ratio       : IN2 = "));
  Serial.print(IN2_TO_IN1_RATIO, 1);
  Serial.print(F("x IN1  -> IN1 takes "));
  Serial.print(IN1_SHARE * 100.0f, 2);
  Serial.println(F("% of total"));
  Serial.print(F("total flow        : "));     Serial.print(TOTAL_IN_UL_MIN, 1);
  Serial.println(F(" uL/min"));

  // Worst case for the step generator: OUT3 handed a 100% split.
  Serial.print(F("fastest pump      : "));     Serial.print(MAX_PUMP_SPS, 1);
  Serial.println(F(" steps/s (OUT3 at 100% split)"));
  Serial.println();
  Serial.println(F("Load INPUT syringes FULL and OUTPUT syringes EMPTY before arming."));
  Serial.println(F("Open the RUN switch, then close it to arm."));
  Serial.println();
}

// Stage one status line. Returns false if the previous one has not drained yet,
// so a slow terminal throttles telemetry instead of stalling the steppers - and
// the caller retries rather than forfeiting the slot.
static bool stageStatus() {
  if (!txIdle()) return false;

  txBegin();

  // Re-emit the column header periodically. Opening the serial monitor after
  // boot otherwise leaves you with unlabelled numbers and no way to see the
  // units short of resetting the board.
  static uint8_t rows = 0;
  if (rows == 0) {
    txStr("\r\nstate   OUT1/OUT2/OUT3 split   then per pump: uL/min (syringe uL)");
    txEol();
  }
  if (++rows >= TELEMETRY_HEADER_ROWS) rows = 0;

  switch (g_state) {
    case ST_IDLE:    txStr("IDLE    "); break;
    case ST_RUNNING: txStr("RUN     "); break;
    case ST_FAULT:   txStr("FAULT   "); break;
  }

  for (uint8_t i = N_INPUTS; i < N_PUMPS; i++) {
    txFloat(g_fraction[i] * 100.0f, 1);
    txStr(i == N_PUMPS - 1 ? "%  " : "/");
  }

  for (uint8_t i = 0; i < N_PUMPS; i++) {
    const float moved = stepsTaken(i) / STEPS_PER_UL;
    // Inputs report what is left in the barrel, outputs what they have taken in.
    const float vol = (i < N_INPUTS) ? (SYRINGE_VOLUME_UL - moved) : moved;

    txStr(" ");
    txStr(PUMP_NAME[i]);
    txStr(" ");
    txFloat(g_flowUlS[i] * 60.0f, 1);
    txStr("(");
    txFloat(vol, 0);
    txStr(")");
  }
  txEol();
  return true;
}

// ---------------------------------------------------------------------------
// Setup / loop
// ---------------------------------------------------------------------------

void setup() {
  Serial.begin(115200);

  for (uint8_t i = 0; i < N_PUMPS; i++) {
    g_pump[i].setMaxSpeed(STEPPER_MAX_SPS);
    g_pump[i].setMinPulseWidth(MIN_PULSE_WIDTH_US);
    g_pump[i].setSpeed(0.0f);
  }

  pinMode(EN_PIN, OUTPUT);
  digitalWrite(EN_PIN, HIGH);   // drivers off until armed
  pinMode(LED_PIN, OUTPUT);
  digitalWrite(LED_PIN, LOW);
  pinMode(BTN_PIN, INPUT_PULLUP);

  // Seed the pot filters from the current position so the first reading is
  // already correct instead of ramping in from zero.
  for (uint8_t p = 0; p < N_POTS; p++) {
    const int raw = analogRead(POT_PIN[p]);
    g_potAcc[p] = (int32_t)raw << POT_EMA_SHIFT;
    g_potApplied[p] = (uint16_t)raw;
  }

  recomputeFlows();
  printBanner();

  // Both speed limits are enforced by static_assert in config.h rather than at
  // runtime, since flow is now fixed. See MAX_PUMP_SPS and MIN_IN1_SPS.
}

void loop() {
  static uint32_t lastControl = 0;
  static uint32_t lastTelemetry = 0;
  static uint32_t lastBlink = 0;

  // Highest priority: every pump gets a chance to step on every pass.
  for (uint8_t i = 0; i < N_PUMPS; i++) g_pump[i].runSpeed();

  txService();

  const uint32_t now = millis();

  const bool wantRun = runSwitchClosed();

  // Never arm on power-up from an already-closed switch: the operator has to
  // open it once first. Without this, restoring power to a rig left switched on
  // starts pumping with nobody present and with the syringe positions assumed
  // rather than known.
  if (!wantRun && g_armInhibit) {
    g_armInhibit = false;
    Serial.println(F("[arm] RUN switch open, ready to arm"));
  }

  switch (g_state) {
    case ST_IDLE:
      if (wantRun && !g_armInhibit) enterRunning();
      break;

    case ST_RUNNING:
      if (!wantRun) enterIdle();
      break;

    case ST_FAULT:
      // A maintained switch has to be physically returned to OFF to clear a
      // fault, which guarantees someone is present for the syringe reload that
      // resetting the volume accounting assumes.
      if (!wantRun) {
        for (uint8_t i = 0; i < N_PUMPS; i++) g_pump[i].setCurrentPosition(0);
        enterIdle();
      }
      break;
  }

  if ((now - lastControl) >= (1000UL / CONTROL_HZ)) {
    lastControl = now;

    if (readPots()) {
      recomputeFlows();
      applySpeeds();      // no-op while idle; applySpeeds() commands zero
    }
    if (g_state == ST_RUNNING) checkTravel();
  }

  if (g_state == ST_FAULT && (now - lastBlink) >= 200) {
    lastBlink = now;
    digitalWrite(LED_PIN, !digitalRead(LED_PIN));
  }

  if ((now - lastTelemetry) >= TELEMETRY_MS && stageStatus()) {
    lastTelemetry = now;
  }
}

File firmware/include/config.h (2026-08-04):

// config.h - all tunable constants for the ufluidics ESP32-S3 controller.
//
// This file holds every number a user would reasonably want to change.
// Everything else in src/ contains logic only and reads from here.
//
// Ported from the AVR build in ../../arduino/ufluidics/. The mechanics,
// syringe and process sections are identical by design - only the pin map,
// the ADC width and the step generator differ.

#pragma once

#include <Arduino.h>

// ---------------------------------------------------------------------------
// Mechanics
// ---------------------------------------------------------------------------

#define MOTOR_STEPS_PER_REV   200      // 1.8 deg/step NEMA17

// Step resolution the TMC2209 is COMMANDED at. Configure the driver for 1/16
// with MicroPlyer interpolation to 1/256: the motion is as smooth as 1/256
// while the step rate stays 16x lower. Setting 256 here instead would multiply
// every rate by 16 for no gain in smoothness.
#define MICROSTEPS            16

#define LEADSCREW_PITCH_MM    2.0f     // mm of carriage travel per motor revolution

// ---------------------------------------------------------------------------
// Syringe
//
// MEASURE YOUR OWN BARREL INNER DIAMETER WITH CALIPERS.
// This single number sets volume-per-millimetre for the whole system, so a
// 1% error here is a 1% error on all five pumps.
//
// NOTE: still one geometry shared by all five pumps. With a 15:1 input ratio
// that gives wildly different barrel lifetimes - see HARDWARE.md. Making these
// per-pump arrays is the outstanding firmware item.
// ---------------------------------------------------------------------------

#define SYRINGE_ID_MM         14.5f    // BD 10 mL Luer-Lok
#define SYRINGE_VOLUME_UL     10000.0f // usable stroke volume

// ---------------------------------------------------------------------------
// Process
// ---------------------------------------------------------------------------

// IN1 flow is fixed - it is the single source of truth. IN2 follows by a fixed
// ratio, and all three output pumps divide the resulting total. That is what
// keeps the system zero-sum.
//
// uL/min throughout, so nothing in this file mixes mL and uL.
#define IN1_FLOW_UL_MIN       70.0f    // -> IN2 1050, total 1120 uL/min
#define IN2_TO_IN1_RATIO      15.0f

// Per-pot ceiling for the two pot-controlled outputs. OUT3 takes whatever is
// left, so its floor is 1 - 2*OUT_POT_MAX_FRAC. Must stay strictly below 0.5.
#define OUT_POT_MAX_FRAC      0.45f

// ---------------------------------------------------------------------------
// Step generator
//
// DDS: each pump owns a 32-bit phase accumulator advanced every timer tick,
// and one step is emitted per accumulator wrap. Average rate is exact to
// DDS_TICK_HZ / 2^32, regardless of how slow the pump runs.
//
// This replaces AccelStepper entirely. No polling, so nothing the main loop or
// the WiFi stack does can cost a step - which was the dominant accuracy
// concern on the AVR build.
// ---------------------------------------------------------------------------

#define DDS_TICK_HZ           20000UL  // also the hard ceiling on steps/s

// Below this a pump is commanded to a true stop rather than an absurd rate.
// Unlike the AVR build this is not an overflow guard - the DDS has no such
// failure mode - it just avoids meaningless sub-microstep-per-hour rates.
#define MIN_SPEED_SPS         0.001f

// TMC2209 needs only ~100 ns of STEP high. The ISR holds it for a few hundred.
#define STEP_PULSE_SPINS      8

// ---------------------------------------------------------------------------
// TMC2209 (UART configured - no Vref trimpot)
// ---------------------------------------------------------------------------

#define TMC_RMS_CURRENT_MA    800      // per motor; 42 mm NEMA17 on a 2 mm screw
#define TMC_UART_BAUD         115200
#define TMC_STEALTHCHOP       true
#define TMC_INTERPOLATE       true     // MicroPlyer: 1/16 commanded -> 1/256 motion

// ---------------------------------------------------------------------------
// Control loop timing
// ---------------------------------------------------------------------------

#define CONTROL_HZ            50UL     // pot read + rate recompute rate
#define TELEMETRY_MS          1000UL   // serial status period
#define TELEMETRY_HEADER_ROWS 20       // re-emit the column header this often
#define DEBOUNCE_MS           25UL     // RUN switch debounce window

#define MOTION_TASK_CORE      1        // core 0 runs the WiFi/TCP stack
#define MOTION_TASK_STACK     4096
#define MOTION_TASK_PRIO      3
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

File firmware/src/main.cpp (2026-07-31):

// ufluidics - zero-sum five-pump syringe controller, ESP32-S3.
//
// Two input pumps push a fixed total flow into the microfluidic device at a
// fixed ratio to each other. Three output pumps withdraw exactly that same
// total, split three ways. Two potentiometers set the output split; a
// maintained switch arms the system.
//
// Because every pump derives from one total, mass balance holds by
// construction rather than by tuning: the three output fractions sum to 1.0
// and both inputs and outputs scale from the same number.
//
// Structure:
//   flow.*    portable arithmetic - ported unchanged from the AVR build
//   motion.*  DDS step generator on a hardware timer
//   main.cpp  I/O, state machine, telemetry
//
// All tunables live in include/config.h.

#include <Arduino.h>

#include "config.h"
#include "flow.h"
#include "motion.h"

// ---------------------------------------------------------------------------
// State
// ---------------------------------------------------------------------------

static State g_state = ST_IDLE;
static Flows g_flows;

// Blocks arming until the RUN switch has been seen open at least once since
// boot. Without it, restoring power to a rig left switched on starts pumping
// with nobody present and with syringe positions assumed rather than known.
static bool g_armInhibit = true;

static PotFilter g_pot[N_POTS];

// ---------------------------------------------------------------------------
// Inputs
// ---------------------------------------------------------------------------

// Debounced position of the maintained RUN switch. Closed to GND on an
// internal pullup reads LOW, so closed = run.
//
// This is a latching switch, not a momentary button: its position IS the
// request, so the state machine follows the level rather than toggling on an
// edge.
static bool runSwitchClosed() {
  static uint8_t  stable = HIGH;
  static uint8_t  last = HIGH;
  static uint32_t lastChange = 0;

  const uint8_t raw = digitalRead(RUN_SWITCH_PIN);
  const uint32_t now = millis();

  if (raw != last) {
    last = raw;
    lastChange = now;
  } else if ((now - lastChange) >= DEBOUNCE_MS) {
    stable = raw;
  }
  return (stable == LOW);
}

// One pot per call, round-robin. Not strictly necessary here - the DDS cannot
// lose a step to a slow loop the way AccelStepper could - but it keeps the
// control task's worst-case iteration short and costs nothing.
static bool readPots() {
  static uint8_t p = 0;

  const bool changed = g_pot[p].update((uint16_t)analogRead(POT_PIN[p]));

  if (++p >= N_POTS) p = 0;
  return changed;
}

static void applyFlows() {
  flowCompute(g_pot[0].fraction(), g_pot[1].fraction(), g_flows);

  if (g_state == ST_RUNNING) {
    motionSetRates(g_flows.stepsPerSec);
  } else {
    static const float stopped[N_PUMPS] = {0, 0, 0, 0, 0};
    motionSetRates(stopped);
  }
}

// ---------------------------------------------------------------------------
// State transitions
// ---------------------------------------------------------------------------

static void enterIdle() {
  g_state = ST_IDLE;
  applyFlows();
  motionEnable(false);
  digitalWrite(LED_RUN_PIN, LOW);
  digitalWrite(LED_FAULT_PIN, LOW);
  Serial.println(F("[state] IDLE"));
}

static void enterRunning() {
  g_state = ST_RUNNING;
  motionEnable(true);
  digitalWrite(LED_RUN_PIN, HIGH);
  applyFlows();
  Serial.println(F("[state] RUNNING"));
}

static void enterFault(uint8_t pump) {
  g_state = ST_FAULT;
  applyFlows();
  motionEnable(false);
  digitalWrite(LED_RUN_PIN, LOW);
  Serial.print(F("[state] FAULT - end of travel on "));
  Serial.print(PUMP_NAME[pump]);
  Serial.println(F(". Reload syringes, then open the RUN switch to acknowledge."));
}

// ---------------------------------------------------------------------------
// Safety
//
// Inputs start full and count down to empty; outputs start empty and count up
// to full. Both reach the same step count, so one integer comparison covers
// every pump with no floating point in the safety path.
//
// TODO: once endstops are fitted, home on startup and turn this from an
// assumption about the starting position into a measurement.
// ---------------------------------------------------------------------------

static void checkTravel() {
  for (uint8_t i = 0; i < N_PUMPS; i++) {
    if (motionSteps(i) >= STEPS_FULL_SYRINGE) {
      enterFault(i);
      return;
    }
  }
}

// ---------------------------------------------------------------------------
// Telemetry
// ---------------------------------------------------------------------------

static void printBanner() {
  Serial.println();
  Serial.println(F("=== ufluidics zero-sum five-pump controller (ESP32-S3) ==="));
  Serial.print(F("microsteps        : 1/"));   Serial.print(MICROSTEPS);
  Serial.println(F(" commanded, interpolated to 1/256 by the driver"));
  Serial.print(F("steps per mm      : "));     Serial.println(STEPS_PER_MM, 2);
  Serial.print(F("uL per mm         : "));     Serial.println(UL_PER_MM, 3);
  Serial.print(F("steps per uL      : "));     Serial.println(STEPS_PER_UL, 4);
  Serial.print(F("uL per step       : "));     Serial.println(1.0f / STEPS_PER_UL, 4);
  Serial.print(F("full stroke steps : "));     Serial.println(STEPS_FULL_SYRINGE);
  Serial.print(F("IN1 flow (fixed)  : "));     Serial.print(IN1_FLOW_UL_MIN, 1);
  Serial.print(F(" uL/min   at "));            Serial.print(MIN_IN1_SPS, 2);
  Serial.println(F(" steps/s"));
  Serial.print(F("IN2 flow (fixed)  : "));     Serial.print(IN2_FLOW_UL_MIN, 1);
  Serial.print(F(" uL/min   at "));            Serial.print(UL_MIN_TO_SPS(IN2_FLOW_UL_MIN), 2);
  Serial.println(F(" steps/s"));
  Serial.print(F("input ratio       : IN2 = ")); Serial.print(IN2_TO_IN1_RATIO, 1);
  Serial.print(F("x IN1  -> IN1 takes "));       Serial.print(IN1_SHARE * 100.0f, 2);
  Serial.println(F("% of total"));
  Serial.print(F("total flow        : "));     Serial.print(TOTAL_IN_UL_MIN, 1);
  Serial.println(F(" uL/min"));
  Serial.print(F("fastest pump      : "));     Serial.print(MAX_PUMP_SPS, 1);
  Serial.print(F(" steps/s  (DDS tick "));     Serial.print(DDS_TICK_HZ);
  Serial.println(F(" Hz)"));
  Serial.println();
  Serial.println(F("Load INPUT syringes FULL and OUTPUT syringes EMPTY before arming."));
  Serial.println(F("Open the RUN switch, then close it to arm."));
  Serial.println();
}
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

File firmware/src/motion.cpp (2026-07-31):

#include "motion.h"

#include <Arduino.h>
#include <esp_arduino_version.h>
#include <soc/gpio_reg.h>

// ---------------------------------------------------------------------------
// Shared with the ISR
// ---------------------------------------------------------------------------

static volatile uint32_t s_phase[N_PUMPS];
static volatile uint32_t s_inc[N_PUMPS];
static volatile uint32_t s_steps[N_PUMPS];

static portMUX_TYPE s_mux = portMUX_INITIALIZER_UNLOCKED;
static hw_timer_t  *s_timer = nullptr;

// Bit position of each STEP pin within the GPIO_OUT1 bank (GPIO32-48).
static uint32_t s_stepBit[N_PUMPS];

// ---------------------------------------------------------------------------
// ISR
//
// Must stay in IRAM and must not touch anything in flash - no digitalWrite, no
// gpio_set_level, no logging. The register writes below are macros over a
// volatile store, which is safe.
// ---------------------------------------------------------------------------

static void IRAM_ATTR ddsIsr() {
  uint32_t pulse = 0;

  for (uint8_t i = 0; i < N_PUMPS; i++) {
    const uint32_t inc = s_inc[i];
    if (inc == 0) continue;

    const uint32_t prev = s_phase[i];
    const uint32_t next = prev + inc;
    s_phase[i] = next;
    if (next < prev) pulse |= s_stepBit[i];   // accumulator wrapped
  }

  if (pulse) {
    REG_WRITE(GPIO_OUT1_W1TS_REG, pulse);     // rising edges, all pumps at once

    for (uint8_t i = 0; i < N_PUMPS; i++) {
      if (pulse & s_stepBit[i]) s_steps[i]++;
    }

    // TMC2209 wants ~100 ns of STEP high. The counting above is not guaranteed
    // to take that long, so pad deterministically rather than hope.
    for (volatile int d = 0; d < STEP_PULSE_SPINS; d++) {
    }

    REG_WRITE(GPIO_OUT1_W1TC_REG, pulse);     // falling edges
  }
}

// ---------------------------------------------------------------------------
// Public
// ---------------------------------------------------------------------------

void motionBegin() {
  for (uint8_t i = 0; i < N_PUMPS; i++) {
    s_stepBit[i] = 1u << (STEP_PIN[i] - 32);

    pinMode(STEP_PIN[i], OUTPUT);
    digitalWrite(STEP_PIN[i], LOW);

    // Direction is fixed for the life of the run, so DIR is stable long before
    // any STEP edge and the driver's setup time is never in question.
    pinMode(DIR_PIN[i], OUTPUT);
    digitalWrite(DIR_PIN[i], DIR_SIGN[i] > 0 ? HIGH : LOW);

    s_phase[i] = 0;
    s_inc[i]   = 0;
    s_steps[i] = 0;
  }

  pinMode(EN_PIN, OUTPUT);
  digitalWrite(EN_PIN, HIGH);   // drivers off until armed

#if ESP_ARDUINO_VERSION_MAJOR >= 3
  // 3.x: frequency in, alarm counted in ticks of that frequency.
  s_timer = timerBegin(DDS_TICK_HZ);
  timerAttachInterrupt(s_timer, &ddsIsr);
  timerAlarm(s_timer, 1, true, 0);
#else
  // 2.x: prescaler from the 80 MHz APB clock, alarm counted in microseconds.
  s_timer = timerBegin(0, 80, true);                       // -> 1 MHz
  timerAttachInterrupt(s_timer, &ddsIsr, true);
  timerAlarmWrite(s_timer, 1000000UL / DDS_TICK_HZ, true);
  timerAlarmEnable(s_timer);
#endif
}

void motionSetRates(const float stepsPerSec[N_PUMPS]) {
  uint32_t inc[N_PUMPS];

  for (uint8_t i = 0; i < N_PUMPS; i++) {
    const float sps = stepsPerSec[i];
    inc[i] = (sps < MIN_SPEED_SPS) ? 0u : (uint32_t)(sps * PHASE_PER_SPS);
  }

  // 32-bit stores are atomic on this core, but the five must land as a set so
  // the ratios between pumps are never briefly wrong.
  portENTER_CRITICAL(&s_mux);
  for (uint8_t i = 0; i < N_PUMPS; i++) s_inc[i] = inc[i];
  portEXIT_CRITICAL(&s_mux);
}

void motionEnable(bool on) {
  digitalWrite(EN_PIN, on ? LOW : HIGH);   // active low
}

uint32_t motionSteps(uint8_t pump) {
  portENTER_CRITICAL(&s_mux);
  const uint32_t v = s_steps[pump];
  portEXIT_CRITICAL(&s_mux);
  return v;
}

void motionResetSteps() {
  portENTER_CRITICAL(&s_mux);
  for (uint8_t i = 0; i < N_PUMPS; i++) {
    s_steps[i] = 0;
    s_phase[i] = 0;
  }
  portEXIT_CRITICAL(&s_mux);
}

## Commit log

2026-07-31 Initial commit: zero-sum five-pump syringe controller
    Firmware for an Elegoo Mega 2560 R3 driving five NEMA17 syringe pumps on a
    microfluidic device. Two input pumps push a fixed total flow at a fixed ratio;
    three output pumps withdraw exactly that same total, split three ways.
    Mass balance holds by construction rather than by tuning: one total-flow
    constant drives both inputs by ratio and all three outputs by fractions that
    sum to 1.0.
    config.h every tunable constant, plus compile-time sanity checks
    ufluidics.ino stepper setup, state machine, flow math, telemetry
    README.md wiring, calibration, verification procedure
    HARDWARE.md PCB spec for the ESP32-S3 revision wit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
    [ufluidics.kicad_pcb, ufluidics.kicad_sch]
2026-07-31 Move KiCad project to hardware/, document repo layout
    The PCB project sat at ufluidics/ufluidics.kicad_pro, nested inside the
    Arduino sketch folder and doubling the project name. hardware/ separates
    the two subsystems clearly.
    Also documents two naming constraints that are easy to trip over:
    the top-level directory must stay named ufluidics for the Arduino IDE to
    open the sketch, and the three KiCad files must keep a shared basename.
    [ufluidics.kicad_pcb, ufluidics.kicad_sch]
2026-07-31 Restructure: split Mega and ESP32-S3 firmware, add PlatformIO project
    Moves the Mega sketch to arduino/ufluidics/ (keeping the directory name the
    Arduino IDE requires) and adds a PlatformIO project for the ESP32-S3 board
    described in HARDWARE.md. Both builds coexist so the Mega rig stays usable.
    The flow math, pot conditioning and state machine port unchanged into
    firmware/src/flow.cpp, which has no hardware calls. What changes is the
    platform layer:
    - AccelStepper polling -> DDS on a 20 kHz hardware timer. Five 32-bit phase
    accumulators, one step per wrap, single GPIO_OUT1 register write for all
    five pumps. Removes the accumulated-lateness error that drove the AVR
    build's no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
    [config.h, main.cpp, motion.cpp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]
2026-07-31 Sync Mega docs and comments to the actual configured flow
    config.h has IN1_FLOW_UL_MIN 70 with a 15:1 ratio, but the comments and the
    README tables still described an earlier 100 uL/min at 10:1. Values were
    right; the prose was stale.
    Actual: IN1 70 uL/min (6.25% of total, 11.3 steps/s), IN2 1050 uL/min
    (93.75%, 169.6 steps/s), total 1120 uL/min, peak 180.9 steps/s.
    Also corrects the barrel-life table - IN2 on a 10 mL syringe is 9.5 min, not
    10 - and the matched-lifetime advice, which wants 15:1 barrel volumes rather
    than 10:1.
    [config.h]
2026-07-31 Make the ESP32-S3 pin map work on N16R8 as well as N16
    Octal PSRAM claims GPIO33-37 for the SPI0/1 data lines. The previous map put
    STEP on 35-39, EN on 34 and a TMC UART on 33, so an R8 module would have
    fought its own memory bus - building fine and then simply not pumping.
    Moves STEP to GPIO38-42 (still contiguous, still in the GPIO_OUT1 bank, so the
    single-register ISR write is unchanged) and relocates EN, both TMC UARTs, the
    RUN switch, E-stop sense and I2C clear of 33-37. 26 pins used: 1 spare on R8,
    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
    [mcu.kicad_sch, ufluidics.kicad_sch]
2026-07-31 Fix SPI display pins: GPIO33/34 do not exist on the WROOM-1 module
    The module exposes GPIO0-21 and GPIO35-48 only - the pad numbering jumps
    straight from IO21 to IO35. GPIO22-25 are absent from the die, 26-32 are bonded
    to the internal flash, and 33/34 are never brought out. The SPI display header
    used 33 and 34, which would have produced schematic nets going nowhere with no
    build error and no DRC violation to catch it.
    Moves the header to GPIO35/36/37/48 and ties display RESET to the board reset
    net, so it needs four GPIO rather than five - which is what makes it fit at all
    now that the spare count is honest.
    Adds a PIN_EXISTS() static_assert over every assigned pin. Verified by
    assigning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
    [config.h]
2026-07-31 Add hardware/CONNECTIONS.md: net-by-net wiring reference
    Full pin-to-pin reference for the ESP32-S3 board. The U1 table is generated
    from firmware/include/config.h and mapped to module pad numbers, so GPIO
    assignments and pad numbers cannot disagree.
    Covers U1, the five TMC2209s with their UART address straps, the power tree,
    and every connector. Also documents the unused-pin handling: GPIO0 needs a
    pullup and boot button rather than a No-Connect, GPIO3/45/46 are NC, and
    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
2026-07-31 Correct a stale GPIO33-37 reference in the BOM notes
2026-07-31 Document the TMC2209 hierarchical sheet layout and fix the VREF note
    Five identical drivers reuse one sheet file. Records which signals cross the
    hierarchy (STEP, DIR, UART, MS1, MS2) and which stay global (power, DRV_EN) or
    inside the sheet (motor connector).
    The catch worth writing down: MS1/MS2 set the UART address, and the four
    drivers sharing bus A each need a different one. Hardwiring them inside a
    reused sheet makes all five identical and collides the bus, so they have to be
    hierarchical pins strapped per instance on the parent.
    Also corrects the VREF row. 'No-Connect' is right for a SilentStepStick, whose
    onboard trimpot already drives the pin, but wrong for a bare TMC2209 where VR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
2026-07-31 Split the TMC2209 wiring by bare IC vs module
    The driver table assumed a SilentStepStick, which hides the charge pump, sense
    resistors and regulator capacitors on the module. A bare QFN-28 needs all of
    them externally, and the pins involved are not optional: VS, VCP, CPI/CPO and
    5VOUT drive the charge pump that generates high-side gate drive, and BRA/BRB
    are the current sense returns.
    Documents both cases, with the pin names that tell them apart, and notes the
    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
    [mcu.kicad_sch, stepper.kicad_sch, ufluidics.kicad_sch]
2026-07-31 Switch the driver spec to socketed modules
    Makes SilentStepStick-style modules on 2x8 female headers the primary case and
    demotes the bare QFN to reference. Removes about forty passives from the BOM -
    charge pump caps, the 5VOUT capacitor and all ten sense resistors are on the
    module. The 100 uF + 100 nF per socket on VMOT stays, since the socket adds
    inductance between the module and the bulk capacitor.
    Documents the two failure modes sockets introduce: a backwards module is
    destroyed instantly and can take the MCU with it, and hot-plugging kills the
    output stage. Both want silkscreen.
    Also records the I_scale_analog gotcha in the firmware TODO. GCONF bit 0
    defaults to 1, so VREF scales t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
    [main.cpp]
2026-07-31 Explain why driver VIO must be 3.3 V, not 5 V
    VIO sets the logic reference, not the operating supply, so 3.3 V costs
    nothing. At 5 V the input threshold rises to ~3.5 V, above what the ESP32 can
    drive, and - the damaging half - PDN_UART is bidirectional, so the driver
    answers register reads at VIO and pushes 5 V into a GPIO that is not 5 V
    tolerant. Both UART pins fan out to five drivers.
    [stepper.kicad_sch]
2026-07-31 Clarify MS1/MS2 role and flag the MRES reset default
    MS1/MS2 select microstepping only in standalone mode. Under UART they are the
    device address, so the four drivers sharing bus A must be strapped
    differently - identical straps collide the bus. Microstepping moves to
    CHOPCONF.MRES in software.
    Also records why 1/16 plus MicroPlyer is the maximum-resolution setting rather
    than a compromise: the motor sees 1/256 either way, but native 1/256 costs 16x
    the step rate for identical smoothness.
    And the trap underneath both: CHOPCONF.MRES resets to 256 microsteps, so a
    driver that never received its config runs 16x slow while the flow math
    believes it is on rate. test_connection() must be checked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
    [main.cpp]
2026-07-31 Document duplicated PDN pads and CLK handling
    The TMC2209 die has one PDN_UART pin, so two module pads labelled PDN are the
    same net - wire one through its 1k and leave the other NC. Two resistors in
    parallel would halve the series impedance the half-duplex line relies on.
    CLK ties to GND for the internal oscillator and must not float next to a 24 V
    chopper. Notes that oscillator tolerance does not affect flow rate, since
    position comes from STEP count and CLK only sets chopper frequency.
2026-07-31 Correct the two-PDN-pad guidance: measure, do not assume
    Previously claimed two PDN pads must be the same net because the die has one
    PDN_UART pin. The premise is right but the conclusion was not: many modules put
    the 1k on-board and break the single die pin out as separate TX and RX pads,
    which is the standard TMC2209 UART arrangement pre-built.
    Documents how to tell them apart (ohmmeter between the pads: ~0 vs ~1k) and
    what each case implies, including that an external 1k must not be stacked on an
    on-board one.
    Also records the pin-budget consequence: split TX/RX needs two GPIO per bus
    instead of one. N16 absorbs that at the cost of the SPI display header; R8 does
    not have the pins.
2026-07-31 Resolve the two-PDN-pad question for BigTreeTech modules
    BTT TMC2209 V1.2/V1.3 breaks PDN_UART out on two alternative pin positions,
    not as TX and RX. Pin 4 is the factory default with the 1k already fitted on
    the module; pin 5 is physically open until that resistor is relocated.
    So: wire pin 4 to the bus, leave pin 5 NC, and add no external resistor - a
    second 1k in series would make 2k. Klipper drives these from a single uart_pin,
    confirming single-wire half-duplex, so the pin budget is unchanged and both the
    SPI display header and the R8 option survive.
    Notes that this is vendor-specific: bare ICs and Watterott SilentStepSticks do
    not carry the resistor, and some modules genuinely split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
    [stepper.kicad_sch, ufluidics.kicad_sch]
2026-07-31 Update U1 table: BTT modules carry the UART series resistor
2026-07-31 Specify the buck and LDO parts, with the thermal math
    Buck: TPS54360 (60 V, 3.5 A). The 40 V minimum rating is the real constraint -
    TPS54331, MP1584, AP63203 and TPS54202 are all 28-32 V parts, and a shorted
    high-side FET on a 24 V motor rail puts 24 V onto the 5 V rail.
    LDO: SOT-223, TLV1117-33 or NCP1117-3.3. The package is the decision, not the
    part number - at 215 mA average from 5 V the dissipation is 0.37 W, peaking
    near 1.0 W on WiFi transmit, which is +91 C average in a SOT-23-5. That rules
    out AP2112K and similar, which are the parts people reach for by default.
    Records the power budget (3.3 V rail 215 mA average, 595 mA peak; only ~53 mA
    drawn from 24 V for all logic) and why th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
2026-07-31 Correct the LDO selection reasoning
    Two errors. 'The package is the decision, not the part number' was sloppy -
    SOT-223 is a package, and the actual requirement is a part rated 600 mA or more
    that can shed 0.37 W on the copper it is given. NCP1117 and TLV1117 come in
    both SOT-223 and DPAK, so the package is a layout choice.
    Also removes the misleading peak-rise column. A package thermal time constant
    is seconds and ESP32 WiFi bursts are milliseconds, so the junction responds to
    the average, not the peak - the +253 C figure for SOT-23-5 was not physical.
    The real disqualifier is +93 C on the 0.37 W average.
    Notes that theta JA depends on the copper pour as much as the package: SOT-223
    range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
2026-07-31 Add TPS54360 pin-by-pin wiring from the datasheet
    Values taken from SLVSBB4G, whose worked design example is itself a 5 V
    output: RT 162k for 600 kHz, FB divider 53.6k/10.2k for 5.004 V against the
    0.8 V reference, 8.2 uH inductor.
    Flags the omission most likely to produce a dead board: the TPS54360 is
    non-synchronous and needs an external catch diode from SW to GND. That pin
    needs both the inductor and the diode.
    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
2026-07-31 Expand the USB-C wiring section
    Full 16-pin receptacle pinout wired as a USB 2.0 device, with the two things
    that most often go wrong: each CC pin needs its own 5.1k pulldown (a shared
    resistor breaks orientation detection and reads as a flaky cable), and the D
    pair appears twice in the receptacle and must be tied per orientation.
    Documents the VBUS decision on a board that also carries 24 V. Recommends a
    Schottky from VBUS to the 5 V rail, which gives a genuinely useful state -
    logic and web UI live on USB alone while the motors cannot move, since the
    drivers have no VM. Notes the buck should be set near 5.1 V so it wins when
    both sources are present.
    Adds USBLC6-2SC6 ESD protection and r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
2026-07-31 Recommend a drop-in module over the discrete buck
    At 215 mA average the logic rail does not justify a discrete switcher. The
    Recom R-78HB5.0-1.0 (9-72 V in, 5 V 1 A, SIP-3, pin-compatible with an LM7805)
    replaces about sixteen components and a critical high-di/dt layout with one
    part, for roughly six dollars more.
    Specifies the 1.0 A version rather than 0.5 A: peak draw is around 595 mA, and
    covering a 95 mA deficit through a 2 ms Wi-Fi burst from bulk capacitance would
    need roughly 1900 uF to keep droop under 100 mV.
    The 9-72 V input range also supplies the voltage margin the discrete section
    argues for, without having to reason about transients on the motor rail.
    Keeps the TPS54360 desi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
2026-07-31 Switch to a low-dropout LDO; specify the VBUS Schottky
    The 1117-family parts previously specified fail the USB-only case. From a
    4.75 V VBUS minimum, a 0.35 V Schottky drop plus ~1 V of 1117 dropout leaves
    3.40 V - only 100 mV of margin. A long cable, tired port or hub eats that, and
    the symptom is an ESP32 resetting during Wi-Fi bursts, which presents as a
    firmware bug.
    AP7361C-33E-13: 140 mV dropout at 300 mA, 1 A, SOT-223, with current limit and
    thermal shutdown. Same package and same 0.37 W, so the thermal analysis is
    unchanged, and margin goes to ~960 mV.
    Also specifies the VBUS Schottky. The binding spec is Vf at 250 mA read off the
    curve, but the non-obvious one is reverse voltage: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
    [power.kicad_sch, ufluidics.kicad_sch, usb.kicad_sch]
2026-07-31 Document LM2675MX-5.0 as the middle buck option
    Sits between the Recom module and a full TPS54360 design: 6.5-40 V, 1 A,
    260 kHz, internally compensated, and the fixed-5.0 V version drops the feedback
    divider. About six external parts against sixteen.
    Records the two caveats. 40 V is the stated minimum rather than comfortable
    margin on a rail shared with five inductive loads - the same argument that ruled
    out TPS54331 and MP1584. And 260 kHz means a bulky inductor, roughly 33 uH to
    hold continuous conduction at the 250 mA load.
    It also still needs a catch diode, so the high-di/dt loop still has to be laid
    out tightly; fewer support parts does not remove that risk.
2026-07-31 Add JLCPCB assembly path for the buck
    The Recom module is SIP-3 through-hole and unlikely to be in JLC's library.
    Documents two routes: mark it DNP and hand-solder three pins after assembly,
    which keeps the 72 V margin and one-part simplicity; or switch to an SMD part
    JLC stocks.
    Lists selection criteria and three candidates to check against the live parts
    library - LM2675MX-5.0 (best if stocked), XL1509-5.0E1 (cheap, near-certain
    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
    [power.kicad_sch, usb.kicad_sch]
2026-07-31 Document LM2675 pin wiring, flag unresolved ON/OFF polarity
    Pinout and the three unambiguous connections: VSW takes the inductor and the
    catch diode cathode, CB takes a 0.01 uF to VSW rather than GND, and FB connects
    straight to the output on the fixed-5.0 version - confirmed by the datasheet
    listing feedback bias current as ADJ-version-only.
    ON/OFF polarity could not be settled. The electrical table specifies standby
    current at ON/OFF = 0 V, implying HIGH = ON, but the symbol carries an overbar
    and the rest of the SIMPLE SWITCHER family is active-low. Recorded as needing
    confirmation against the datasheet's typical application figure.
    Two constraints hold regardless and both are destructi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
2026-08-03 make the schematics
    [endstops.kicad_sch, leds.kicad_sch, pots.kicad_sch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]
2026-08-03 place the stuff on the pcb
    [endstops.kicad_sch, leds.kicad_sch, pots.kicad_sch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]
2026-08-04 exported lets try
    [ufluidics.kicad_pcb]
